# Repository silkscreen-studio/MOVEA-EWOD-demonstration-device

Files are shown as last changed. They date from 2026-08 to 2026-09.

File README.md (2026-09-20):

# MOVEA, an EWOD demonstration device

EWOD (ElectroWetting On Dielectric) is a fascinating process that moves droplets of water over an electrode array (dielectric as a medium), thanks to a high voltage (100+ V) applied between 2 adjacent cells (coplanar capacitance). **MOVEA** is a minimal 4x4 EWOD array with the complete driver board to demonstrate the basic principle of electrowetting. Based around an ESP32-C3, a DC DC boost converter module (168V OUT) as well as the HV509 driver IC. All inside a fully enclosed 3D printed device. 

<p align="center">
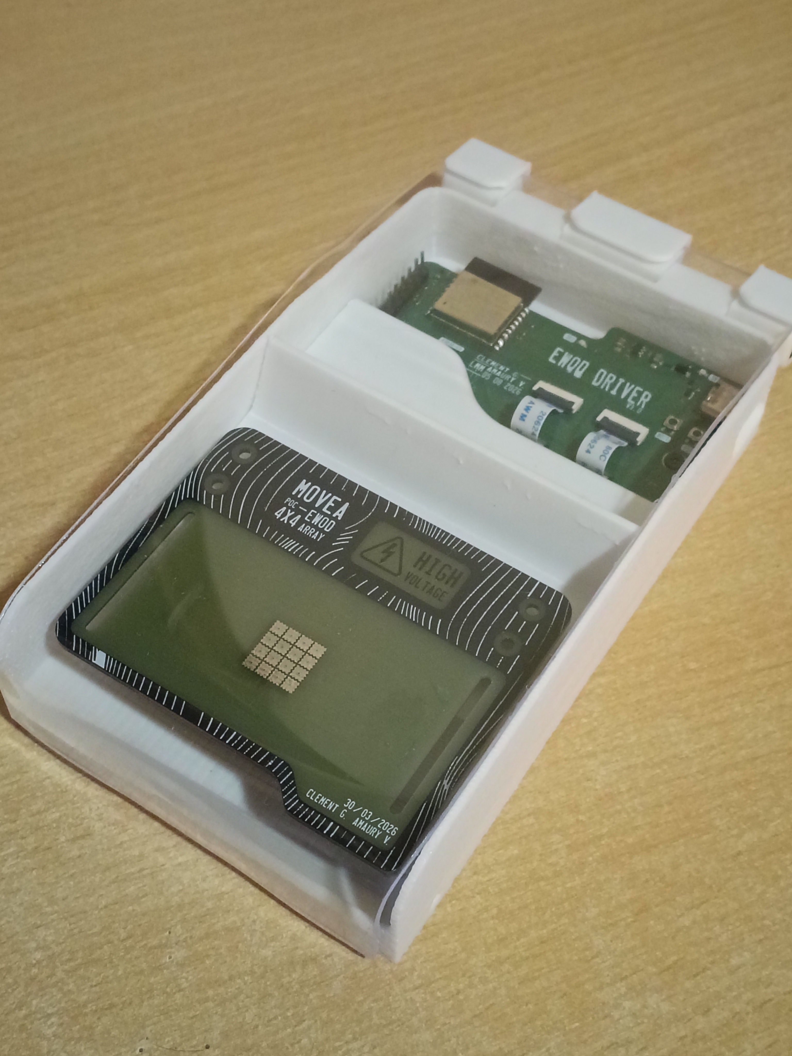
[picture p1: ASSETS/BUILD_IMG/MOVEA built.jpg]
MOVEA BUILT

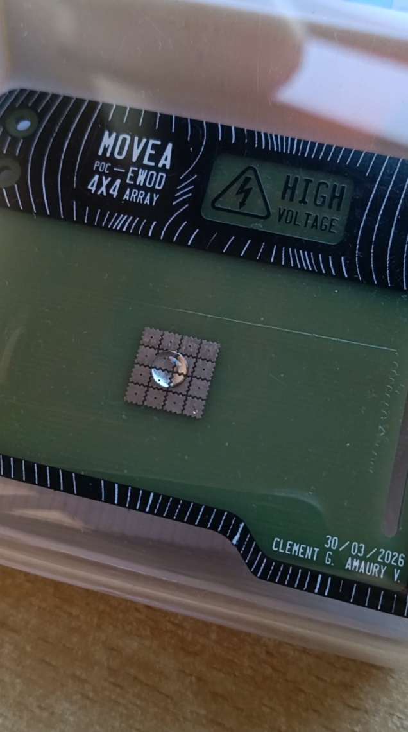
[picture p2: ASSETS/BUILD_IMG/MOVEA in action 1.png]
MOVEA in action

</p>

> [!CAUTION]
> **HIGH VOLTAGE**
>
> This project generates high voltage (~168V DC) from the USB C to correctly drive the EWOD electrodes.
> While I tried my best to provide a fully enclosed design with the HV part being detachable from the MCU circuitry, the high voltage side remains **not galvanically isolated** from the MCU side. Treat the whole board as live whenever `HV OUT` is enabled, not just HV traces.
>
> The USB isn't galvanically isolated either, so it's recommended to fully disconnect the 2 FPC ribbon cables when programming the device to prevent any USB port damage in case of a failure. Controlling the device (droplet actuation) could then be done over WIFI.

> [!WARNING]
>
> **A few safety notes:**
> 
> Although I tried to design a fully enclosed device, the acrylic cover does not latch. Whenever high voltage is enabled, it is the user's responsibility to keep the acrylic door shut.
>
> I still added a 220k serie resistor right after the HV boost, which should limit the output current to completely safe levels of 750µA, but obviously the best practice is to not touch anything when the `HV` Rail is enabled.
>
> While the firmware demo already enforces this (could not be the case if a custom firmware is flashed). It is important to only enable the high voltage when actively actuating the droplets, and the `HV OUT` rail capacitors should be discharged in firmware after the HV module is disabled, to ensure `HV OUT` collapses instead of staying at 168V (the electrodes barely sink any current on their own). Collapsing `HV OUT` should obviously be done before switching the device off (because otherwise the N channel mosfet in charge of sinking `HV OUT` to ground won't conduct).

> [!WARNING]
> **No warranty, use at your own risk**: This project is provided as-is, without any guarantee of safety, correctness, or fitness for any purpose. If you do build, reproduce, adapt or take inspiration from this project, it's entirely at your own risk.
>
> I disclaim all responsibility for any damage, injury or other consequences arising from the use, reproduction, or modification of this design.

> [!NOTE]
> **Educational / demo purpose only** This project is intended for educational / demo purpose only, with no intent of being  used in actual lab experiments.

<br><br>

<br><br>
<br><br>

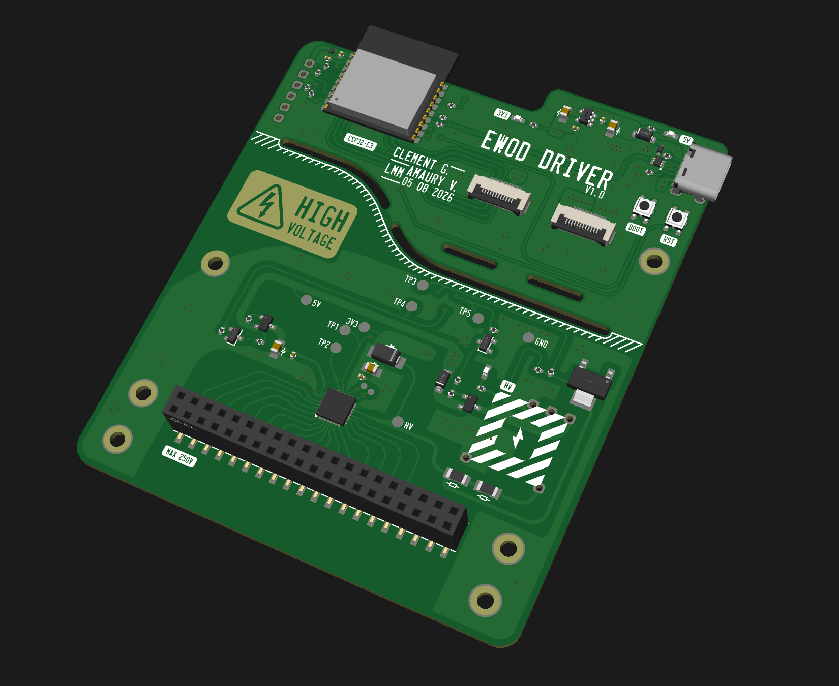
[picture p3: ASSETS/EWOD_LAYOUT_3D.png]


# What is EWOD?

Electrowetting is a fascinating branch of microfluidics, making possible to move droplets of water based solutions (µLiters of solutions) onto a flat surface without any mechanical part. EWOD has application in the biology industry (laboratories, ''lab on chip'') and in optical systems. By controlling each electrode with a 100+ V High voltage, the droplet position onto the EWOD grid can be controlled. 

# What this project aims to provide

This project is a minimal 4x4 EWOD device, with the FR4 EWOD array and the proper high voltage driver. The goal isn't to provide a finished lab-on-chip device with reservoirs and lab precision, but instead to obtain a small EWOD array that can move droplets on the 4x4 grid, showing the working principle of Electrowetting. Multiple dielectrics and different driving schemes could be used to evaluate different properties of electrowetting.

# Demos:

https://www.youtube.com/shorts/SwbNJbgiKzs

https://www.youtube.com/watch?v=05vwhufC6Lg

# Key features:

 - ESP32-C3 MCU
 - HV509 16 CH push pull HV driver
 - 3.3V-12V IN 168V OUT DC DC High voltage converter module
 - VIN enabled `HV OUT` rail (AO3415A P channel Mosfet)
 - 2x110k serie resistor directly on the HV boost output: should limit the current to a safe 750µA (in case of a downstream short circuit)
 - same 2x110k acting as bleeding resistors, sinking `HV OUT` to GND until the MCU disables it.
 - 2 FPC ribbon cables to be able to disconnect all HV related circuitry from the ESP32 devboard
 - detachable EWOD cartridge, that connects thanks to 2x20P 2.54mm Dupont Header pins.
 - 3D printed enclosure with acrylic cover to see the water droplet through the window.

# Schematic:

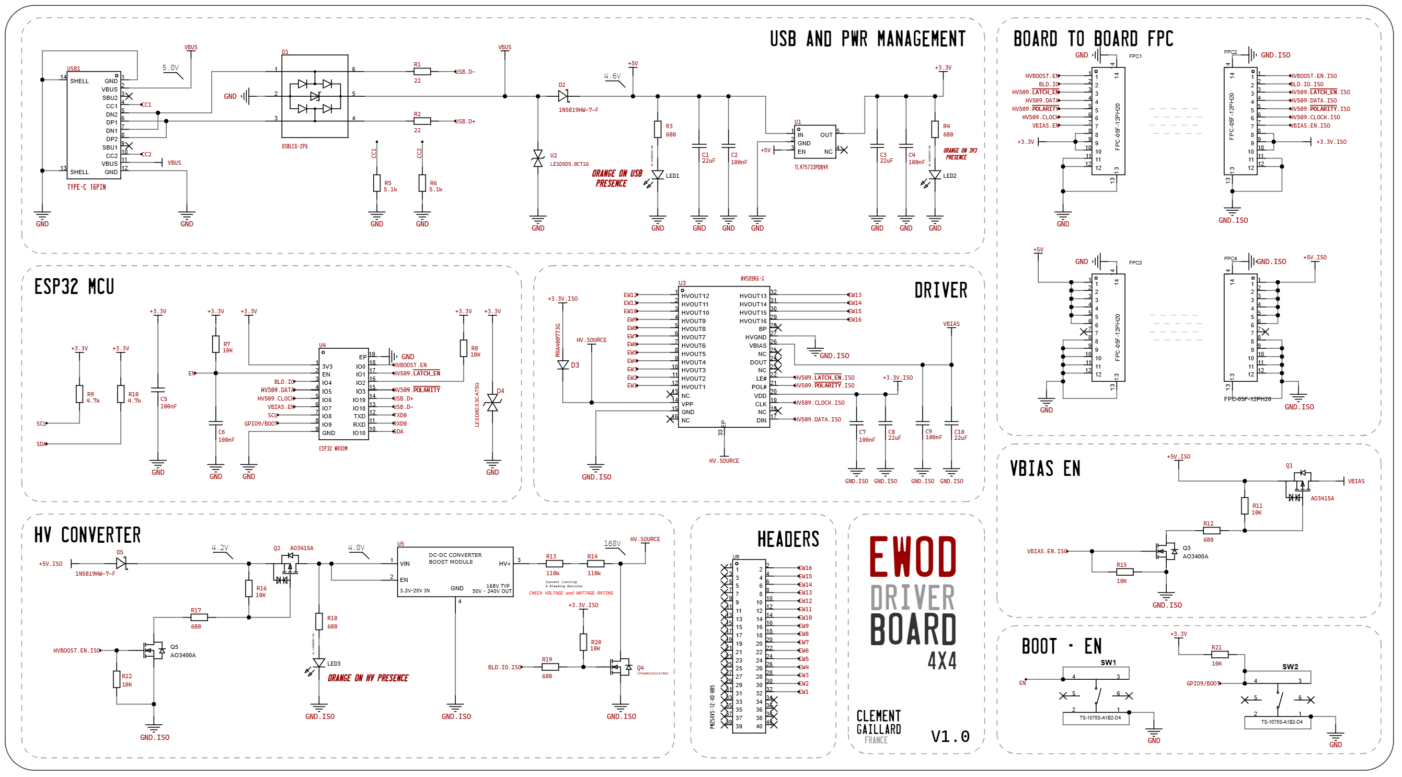
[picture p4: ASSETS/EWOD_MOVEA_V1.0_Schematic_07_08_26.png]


# Layout:

<p align="center">
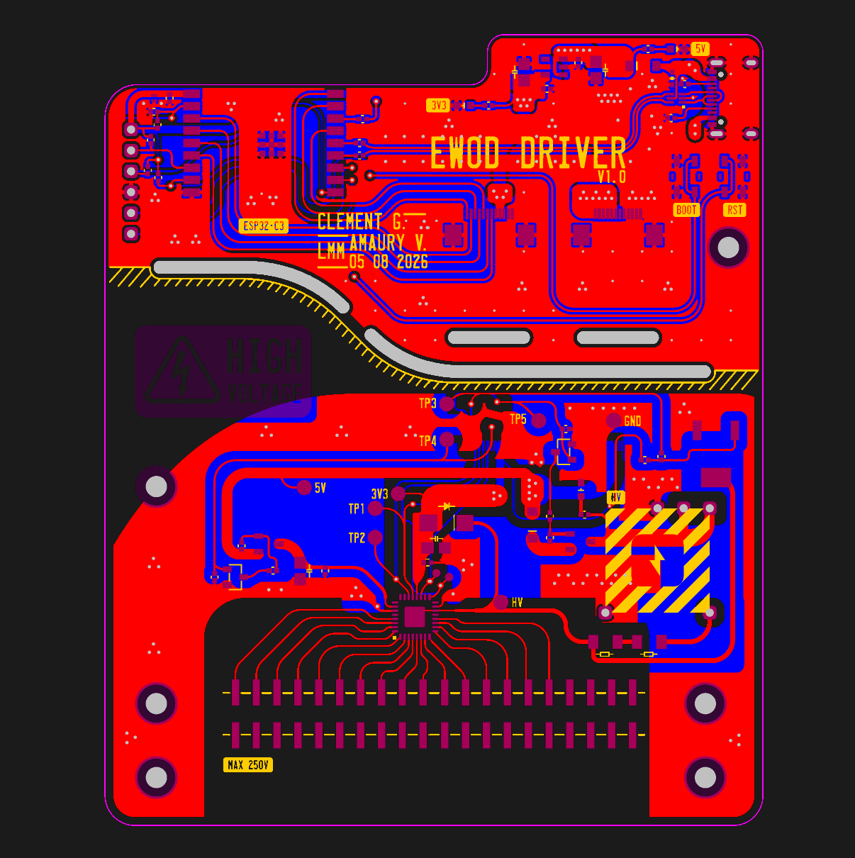
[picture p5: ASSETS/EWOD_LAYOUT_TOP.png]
Top layout

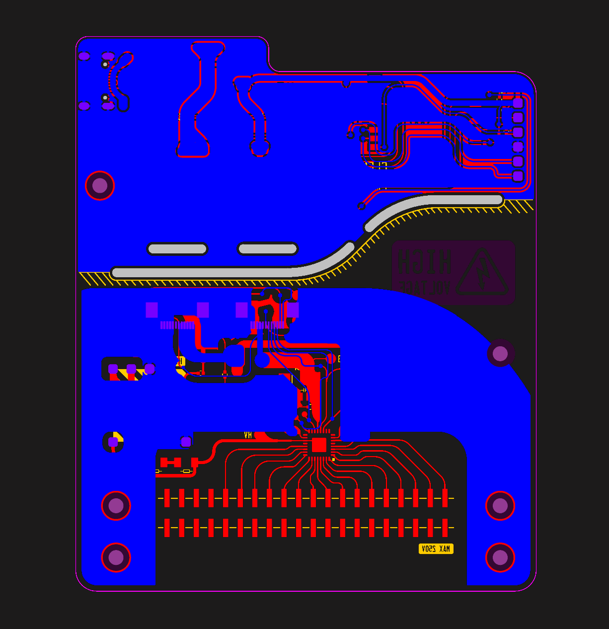
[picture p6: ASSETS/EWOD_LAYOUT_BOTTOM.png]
bottom layout

</p>

# Firmware:

A minimal demo code in C++ (Arduino IDE) is available to interface the HV509 as well as controlling the different power mosfets.

# Enclosure Assembly:

After 3D printing the different parts, cutting a 78.5mm long Φ 6mm steel rod and creating the acrylic window (2mm rectangle cut from an acrylic sheet, then bent with a hot air gun), the device can be assembled:
After connecting the 2 FPC ribbon cables, the PCB can be securely mounted to the enclosure thanks to threaded inserts added beforehand, and the HV cover can be glued in place (held in place with the 2 side rails). for the window, it's recommended to create a 'chain' with all the hinges placed on the enclosure with the rod in the middle, before gluing the acrylic window to the 3 hinge parts.

> [!NOTE]
> **POST BUILD EDIT**
> Bending the acrylic with the hot air gun wasn't really easy, the round 90° angle turned out pretty good, but the 10° angle near the hinge ended up offset...

<br><br>

<p align="center">
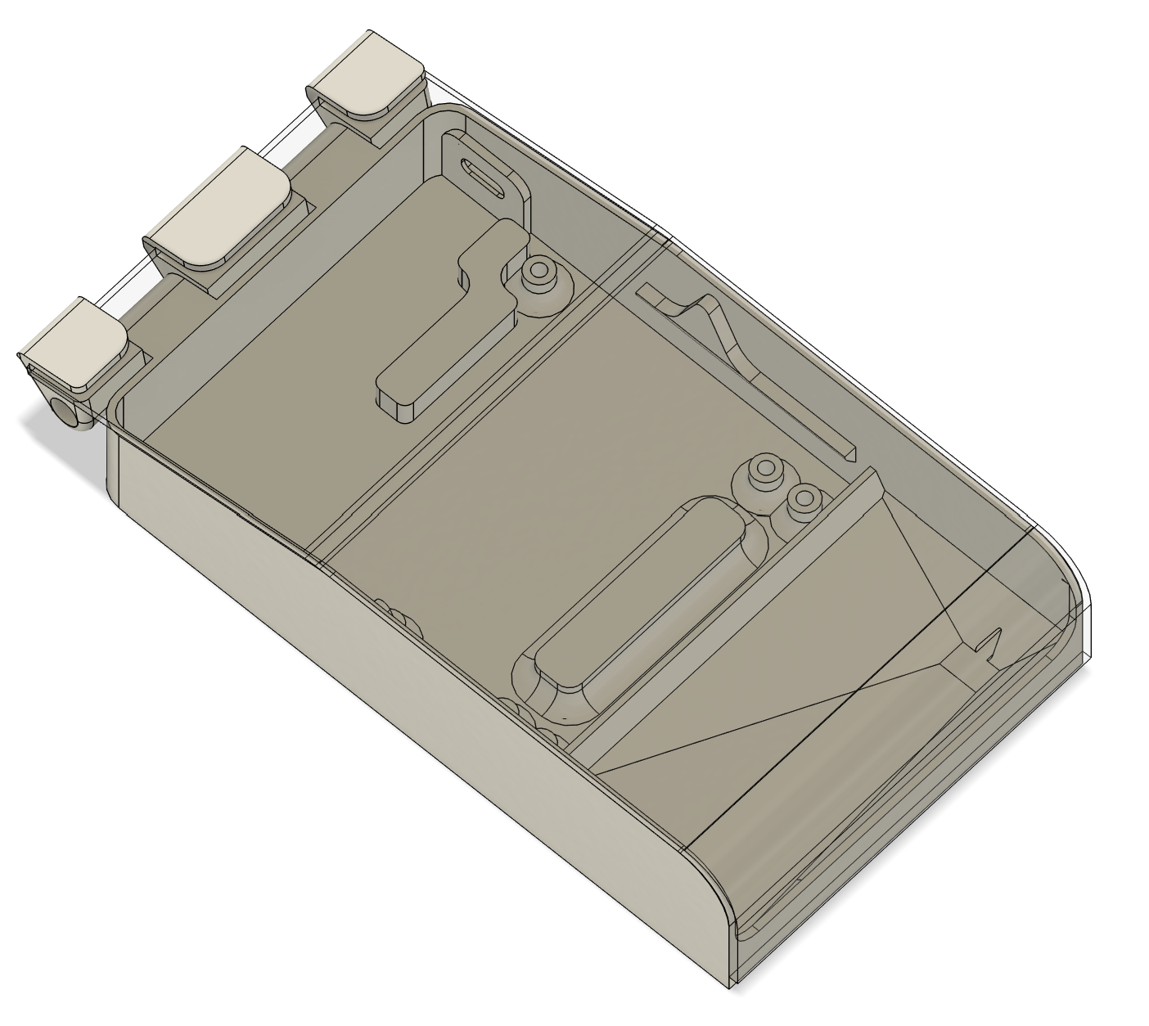
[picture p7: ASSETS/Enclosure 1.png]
3D Enclosure IMG 1

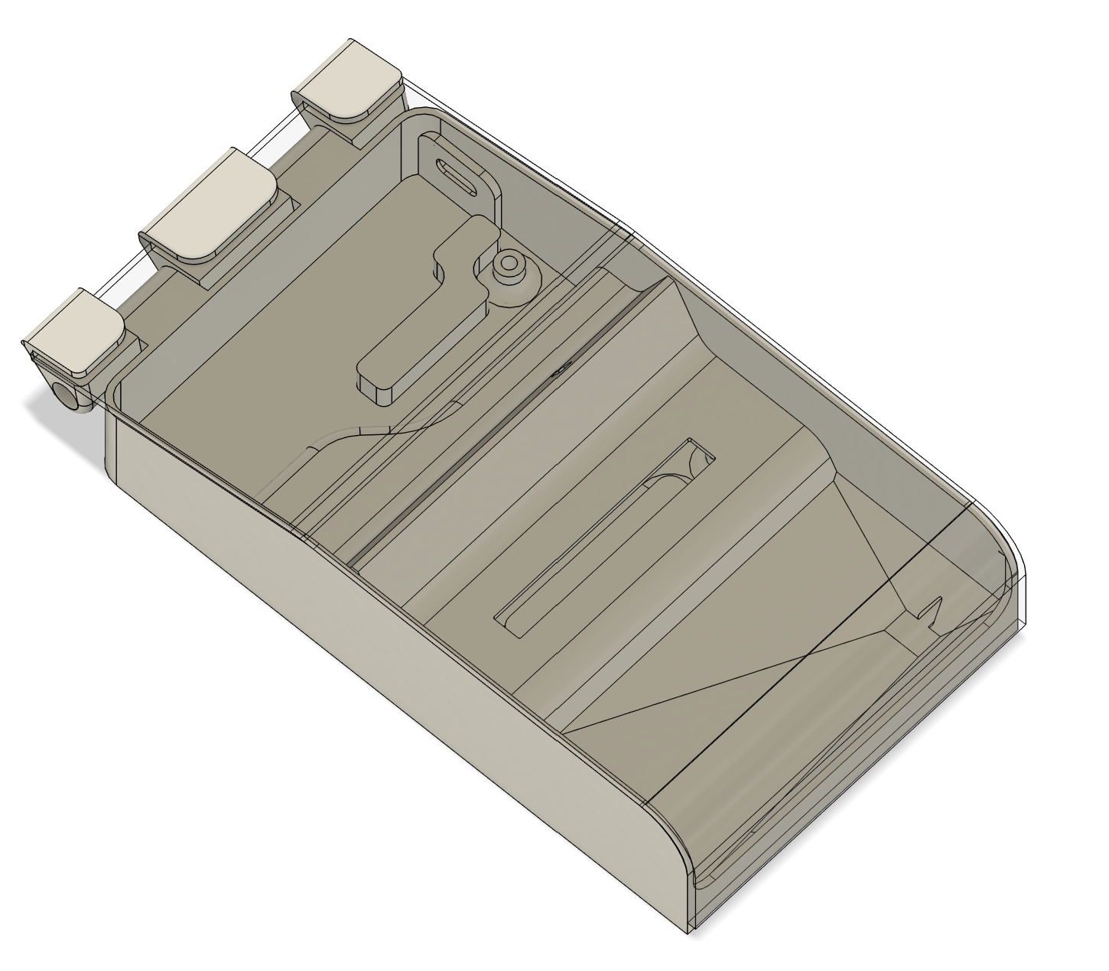
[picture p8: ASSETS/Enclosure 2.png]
3D Enclosure IMG 2

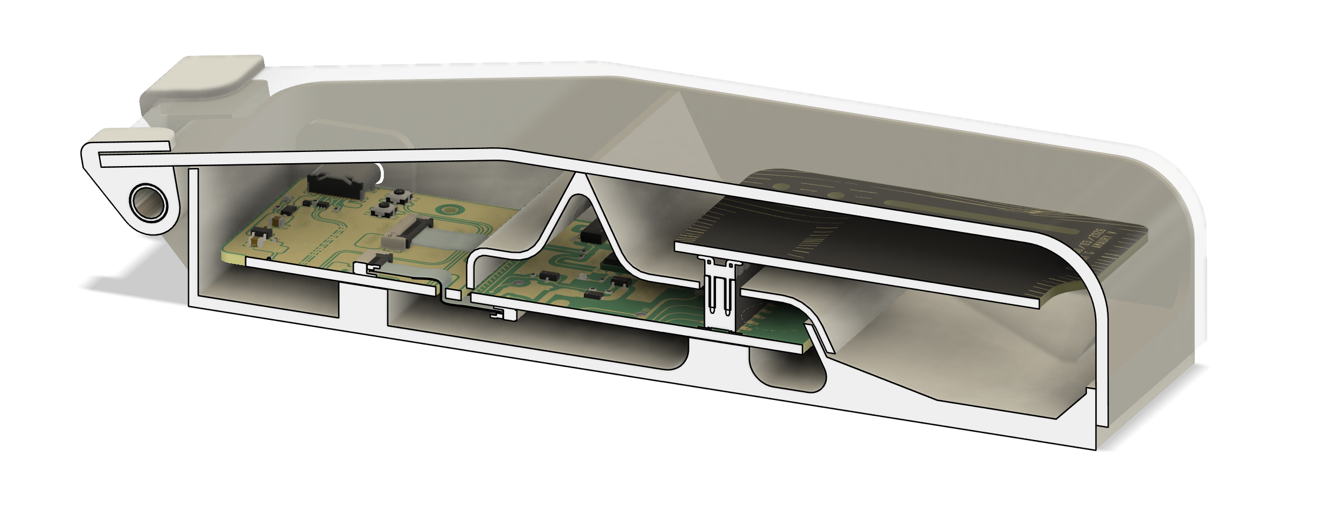
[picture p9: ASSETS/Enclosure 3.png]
3D Enclosure IMG 3

</p>
<p align="center">
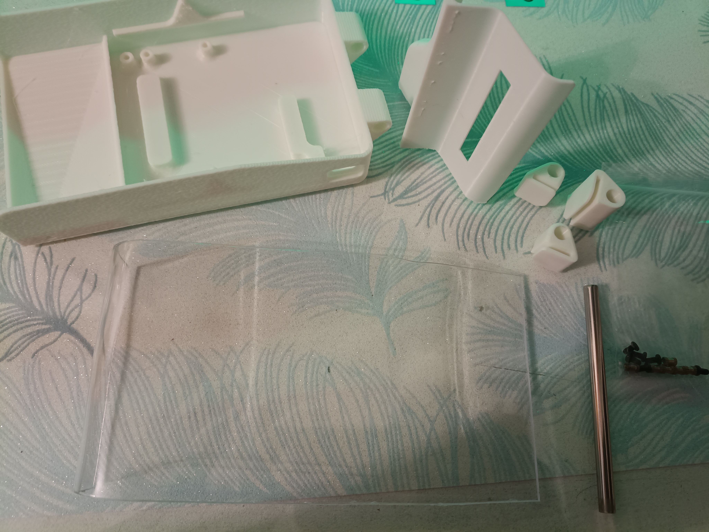
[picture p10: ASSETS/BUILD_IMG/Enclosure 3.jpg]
BUILD Enclosure IMG 3

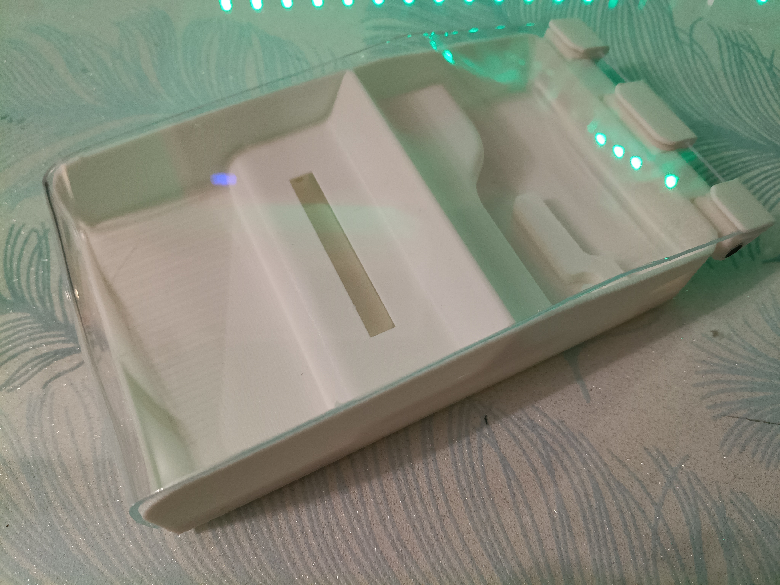
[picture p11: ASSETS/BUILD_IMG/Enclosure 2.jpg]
BUILD Enclosure IMG 2

</p>
<p align="center">
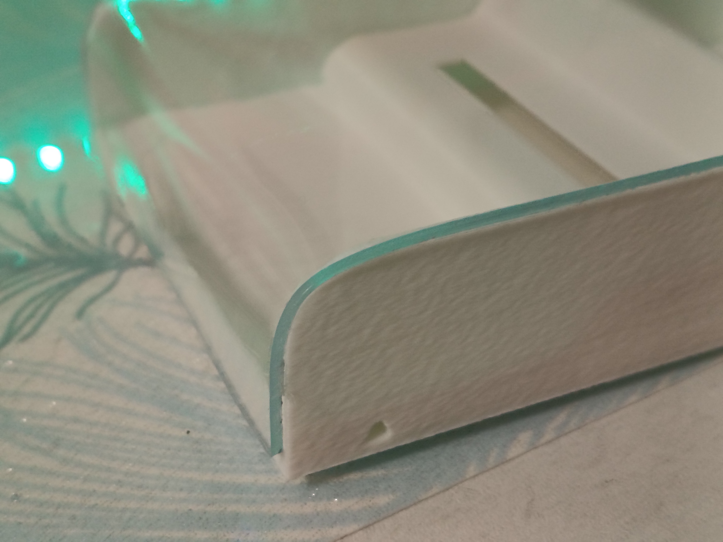
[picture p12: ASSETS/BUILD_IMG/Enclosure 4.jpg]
BUILD Enclosure IMG 4

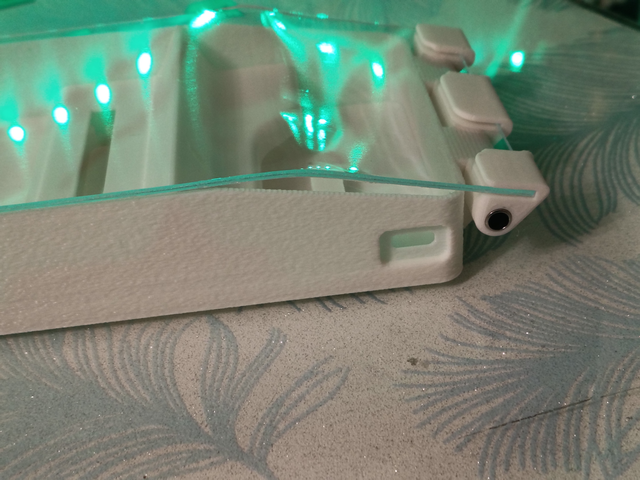
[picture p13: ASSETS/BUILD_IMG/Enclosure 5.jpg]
BUILD Enclosure IMG 5

</p>

<p align="center">
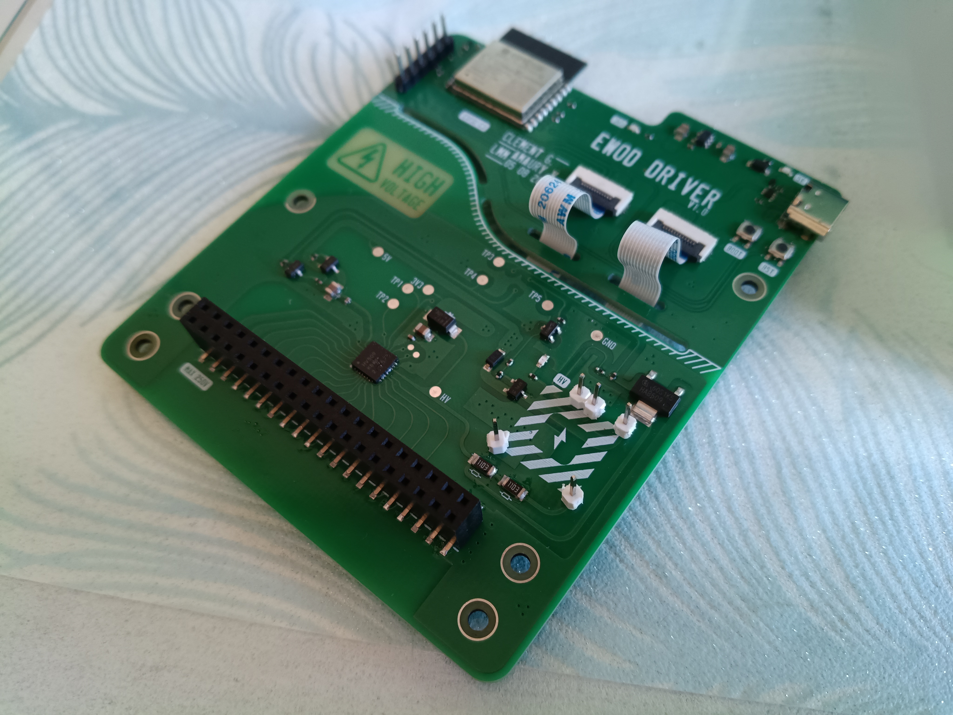
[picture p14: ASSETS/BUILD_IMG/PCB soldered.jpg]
PCB soldered

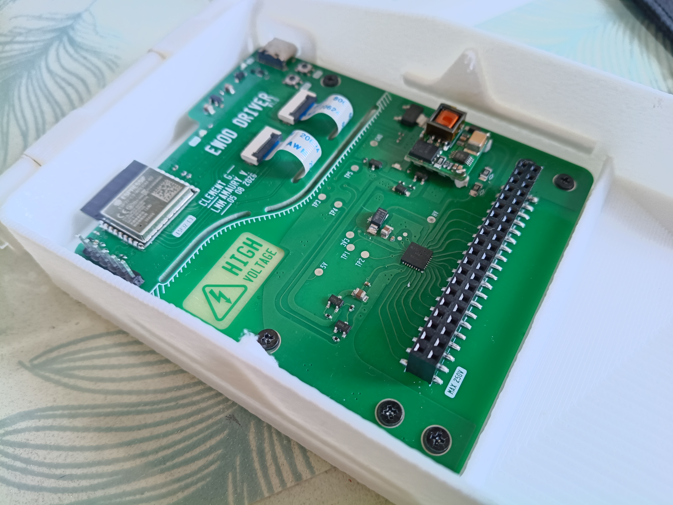
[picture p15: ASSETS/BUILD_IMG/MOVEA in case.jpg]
PCB in case

</p>

MOVEA built

# Preparing the device

the following sequence is for safely programming the device, and preparing the EWOD array.

 - Before plugging any USB power source, make sure the 2 FPC cables are disconnected (only connected on one end, at the bottom side of the board)
 - The ESP32 part only can then be programmed over USB (completely disconnected from any HV related circuitry, thus ensuring no failure can damage the USB port). To do so, plug the USB C cable, hold the BOOT button, press the RST button, release BOOT then flash the firmware. Disconnect the USB cable.
 - Prepare the EWOD PCB: after adding a thin layer of low viscosity silicon oil (5cst), stretch a piece of ParafilmM to be applied over the electrode Array, then after adding an additionnal thin oil layer and plugging the array PCB on the device, a small droplet of water (barely larger than an electrode) can be pladed on the array, then discharged from any residual static charge with a GND wire
 - Carefully reconnect both FPC cables, and close the acrylic cover before reconnecting a USB power source

> [!NOTE]
> **POST BUILD EDIT**
>   I couldn't stretch the parafilm correctly, so it obviously didn't work. However when testing other films I had at home, desk scotch worked quite well... This 31µm thin scotch was giving decent results (the actuation was a bit slow) but  with a proper 10 or 5µm dielectric film it should work even better. I'm planning on trying BOPP film and kapton tape. Both should work better.

# Render:

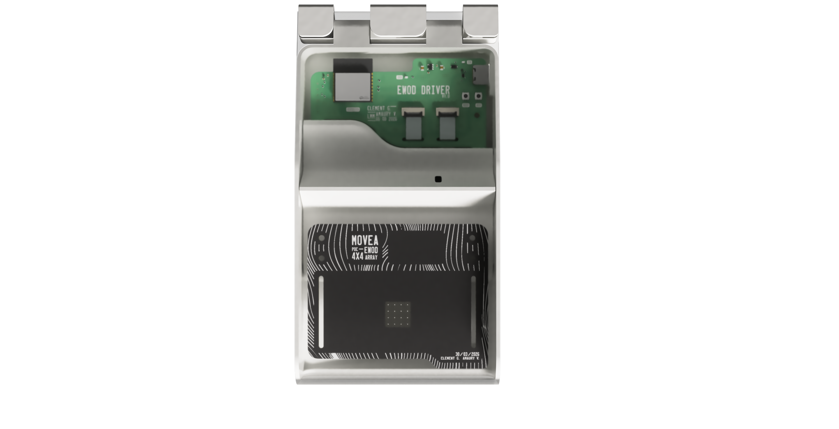
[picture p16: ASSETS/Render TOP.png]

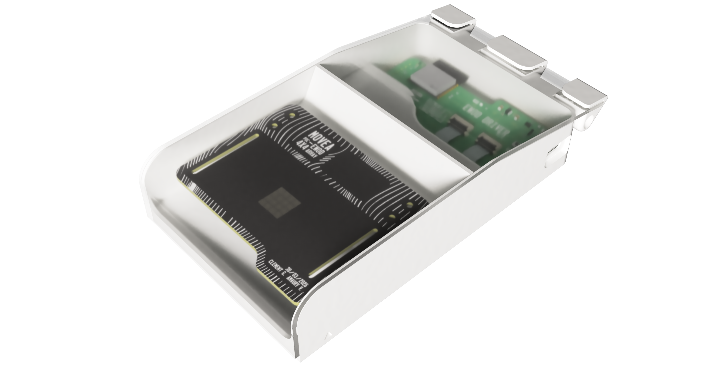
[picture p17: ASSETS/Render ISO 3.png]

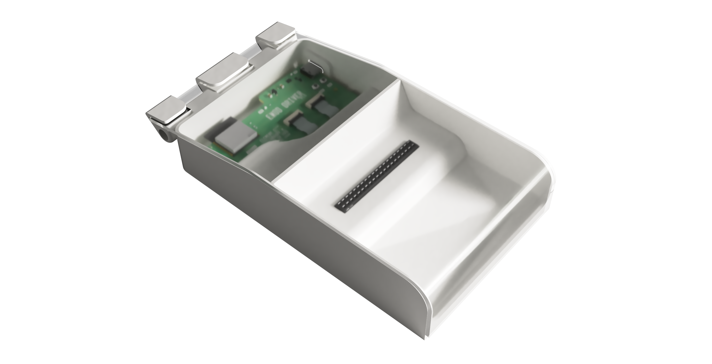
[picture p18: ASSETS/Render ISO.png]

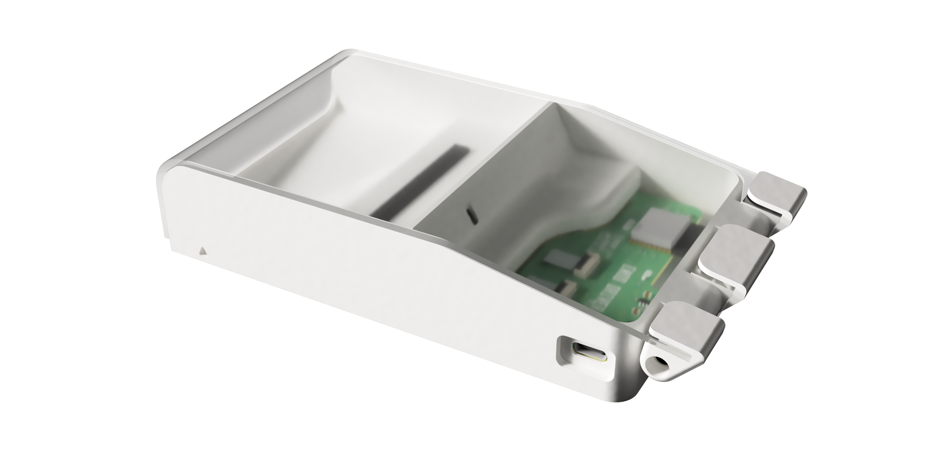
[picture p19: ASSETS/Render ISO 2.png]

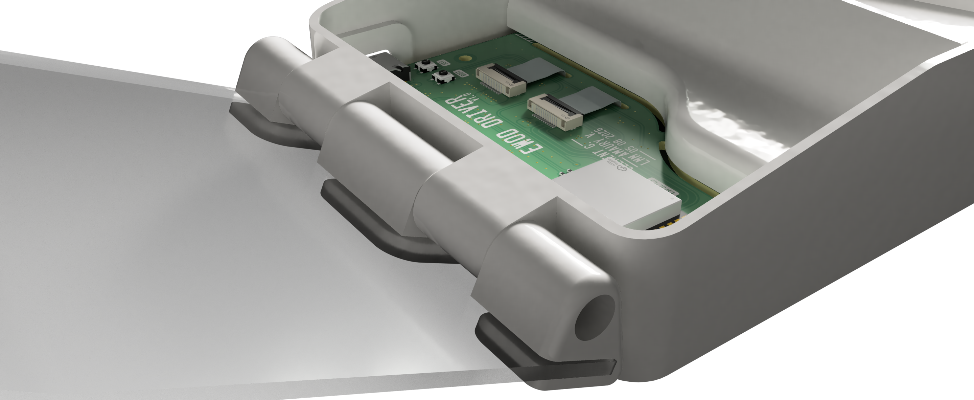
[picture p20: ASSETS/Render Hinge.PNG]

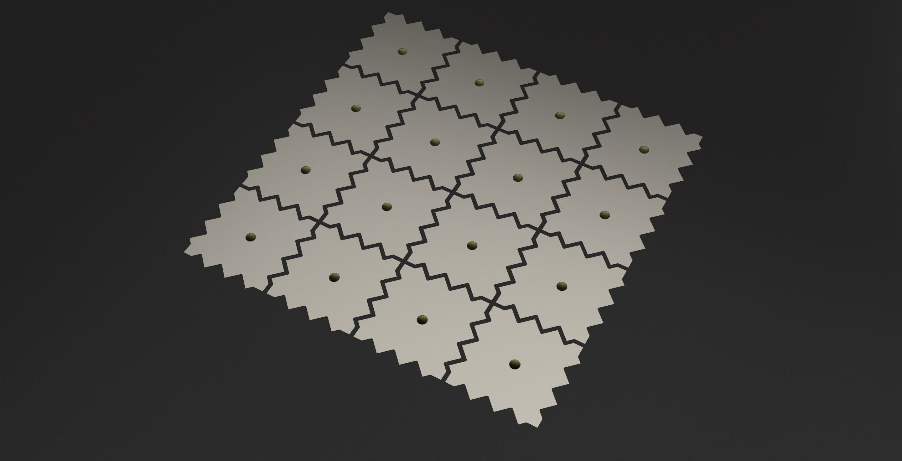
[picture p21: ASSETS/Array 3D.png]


# BOM

|Item |Quantity|Designator |Value |Manufacturer Part |LCSC Part|Link |Price [MOQ] |Total Price (1 board & 5 cartridge)|
|---|---|---|---|---|---|---|---|---|
|MLCC 0805 |4 |C1 C3 C8 C10 |22uF |CL10A226MP8NUNE |C86295 |https://www.lcsc.com/product-detail/C86295.html |$ 0.0537 [10] |$ 0.06 |
|MLCC 0402 |6 |C2 C4 C5 C6 C7 C9 |100nF |CL05B104KB54PNC |C307331  |https://www.lcsc.com/product-detail/C307331.html |$ 0.0096 [100]|$ 0.96 |
|USB ESD |1 |D1 | |USBLC6-2P6 |C15999 |https://www.lcsc.com/product-detail/C15999.html |$ 0.2787 [5]  |$ 1.39 |
|DIODE |2 |D2 D5 | |1N5819HW-7-F |C82544 |https://www.lcsc.com/product-detail/C82544.html |$ 0.0568 [10] |$ 0.57 |
|HV DIODE |1 |D3 | |MRA4007T3G |C47921 |https://www.lcsc.com/product-detail/C47921.html |$ 0.0942 [10] |$ 0.94 |
|ESD DIODE |1 |D4 |3.3V |LESD8D3.3CAT5G |C5563754 |https://www.lcsc.com/product-detail/C5563754.html |$ 0.0090 [20] |$ 0.18 |
|FPC Connector |4 |FPC1 FPC2 FPC3 FPC4 | |FPC-05F-12PH20 |C2856799 |https://www.lcsc.com/product-detail/C2856799.html |$ 0.1079 [5]  |$ 0.54 |
|Orange LED |3 |LED1 LED2 LED3 | |XL-1608UOC-06 |C965800  |https://www.lcsc.com/product-detail/C965800.html |$ 0.0068 [100]|$ 0.68 |
|P Mosfet |2 |Q1 Q2 | |AO3415A |C133233  |https://www.lcsc.com/product-detail/C133233.html |$ 0.1033 [5]  |$ 0.52 |
|N Mosfet |2 |Q3 Q5 | |AO3400A |C20917 |https://www.lcsc.com/product-detail/C20917.html |$ 0.0849 [5]  |$ 0.42 |
|HV N Mosfet |1 |Q4 | |IPN60R1K5CEATMA1 |C3288802 |https://www.lcsc.com/product-detail/C3288802.html |$ 0.5529 |$ 0.56 |
|Chip Resistor 0402 |2 |R1 R2 |22 |AC0402JR-0722RL |C144722  |https://www.lcsc.com/product-detail/C144722.html |$ 0.0027 [100]|$ 0.27 |
|Chip Resistor 0402 |6 |R3 R4 R12 R17 R18 R19 |680 |RC0402FR-07680RL |C137948  |https://www.lcsc.com/product-detail/C137948.html |$ 0.0054 [100]|$ 0.54 |
|Chip Resistor 0402 |2 |R5 R6 |5.1k |RC-02K512JT |C453708  |https://www.lcsc.com/product-detail/C453708.html |$ 0.0027 [100]|$ 0.27 |
|Chip Resistor 0402 |8 |R7 R8 R11 R15 R16 R20 R21 R22|10K |RC0402JR-7W10KL |C851859  |https://www.lcsc.com/product-detail/C851859.html |$ 0.0045 [100]|$ 0.45 |
|Chip Resistor 0402 |2 |R9 R10 |4.7k |RC0402FR-074K7L |C105871  |https://www.lcsc.com/product-detail/C105871.html |$ 0.0043 [100]|$ 0.43 |
|HV Chip Resistor 1206 200V 250mW rated|2 |R13 R14 |110k |RT1206BRD07110KL |C870372  |https://www.lcsc.com/product-detail/C870372.html |$ 0.073 [10]  |$ 0.73 |
|Push-button |2 |SW1 SW2 | |TS-1075S-A1B2-D4 |C492872  |https://www.lcsc.com/product-detail/C492872.html |$ 0.067[10] |$ 0.67 |
|3V3 LDO |1 |U1 | |TLV75733PDBVR |C485517  |https://www.lcsc.com/product-detail/C485517.html |$ 0.2067[5] |$ 1.03 |
|ESD DIODE |1 |U2 |5V |LESD5D5.0CT1G |C7433850 |https://www.lcsc.com/product-detail/C7433850.html |$ 0.0148 [50] |$ 0.74 |
|HV Driver IC |1 |U3 | |HV509K6-G |C633266  |https://www.lcsc.com/product-detail/C633266.html |$ 4.3112 |$ 4.32 |
|MCU |1 |U4 |ESP32 WROOM |ESP32-C3-WROOM-02-N4|C2934560 |https://www.lcsc.com/product-detail/C2934560.html |$3.2954 |$3.30 |
|USB-C 16P |1 |USB1 | |TYPE-C 16PIN |C2765186 |https://www.lcsc.com/product-detail/C2765186.html |$ 0.0707 [20] |$ 1.41 |
|Female Header PIN |1 |U6 |2x20 |PM254VS-12-40-H85 |C5249780 |https://www.lcsc.com/product-detail/C5249780.html |$ 0.6594 |$ 0.66 |
|Male Header PIN (cartridge) |1 | |2x20 |PZ254-2-20-S |C3294478 |https://www.lcsc.com/product-detail/C3294478.html |$ 0.4758 |$ 2.38 |
| | | | | | | | | |
|BOOST converter | 1 | U5 | 168V OUT | | |https://fr.aliexpress.com/item/1005009055927625.html|$ 10.25 | $ 10.25 |
| | | | | | | | | |
|PCB Driver |1 | | | | |https://jlcpcb.com |$ 8.37 |$ 8.37 |
|PCB EWOD array |1 | | | | |https://jlcpcb.com |$ 8.37 |$ 8.37 |
|Metal Rod (hinge) Φ 6mm L >75mm | | | | | |https://fr.aliexpress.com/item/1005009347568195.html|$ 4.33 |$ 4.33 |
|3D Printed enclosure | | | | | | | | |
|2mm acrylic sheet | | |(min 200x100mm)| | | | | |
| | | | | | | | | |
| | | | | | |TOTAL | |$ 55.31 |

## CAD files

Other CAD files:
3D CAD/EWOD_MOVEA_driver_3D_model_05_08_26.step
3D CAD/EWOD_Movea_3DP_only.step
3D CAD/3D PCB Driver EWOD MOVEA V1.1.step
3D CAD/EWOD_MOVEA_driver_3D_model_05_08_26_FUSION360_files.f3z

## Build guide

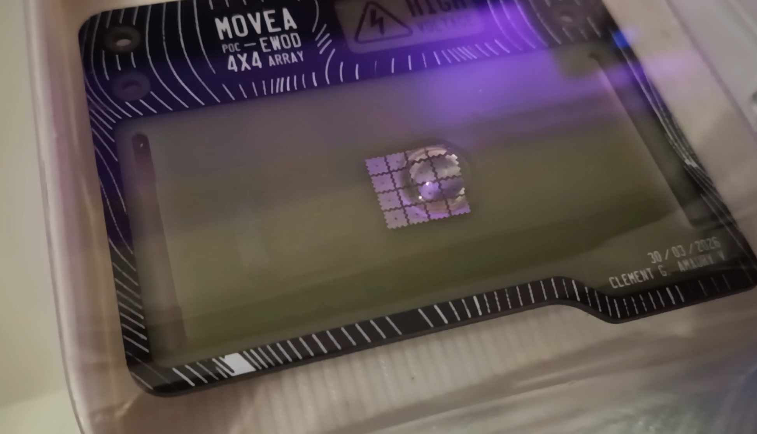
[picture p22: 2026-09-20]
ASSETS/BUILD_IMG/MOVEA in action 2.png

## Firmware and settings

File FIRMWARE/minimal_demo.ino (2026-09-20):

//    Minimal function implementation for driving the EWOD device.
//    By Clément G. - Silkscreen Studio - https://github.com/silkscreen-studio/MOVEA-EWOD-demonstration-device
//    Implements the HV509 shift register manipulation, HV boost proper enabling/disabling (including `HV OUT` 0V clamping management), and frequency-driven polarity inversion (AC actuation)

#define BLD_IO 4
#define VBIAS_EN 7
#define HVBOOST_EN 0

#define DATA 5
#define CLOCK 6
#define N_LATCH_EN 1
#define N_POLARITY 3

bool pol = 1;

void setup() {
  pinMode (BLD_IO, INPUT);    // HI-Z, pull up keeping the Bleeding Mosfet conducting

  pinMode (VBIAS_EN, OUTPUT);
  digitalWrite (VBIAS_EN, LOW);

  pinMode (HVBOOST_EN, OUTPUT);
  digitalWrite (HVBOOST_EN, LOW);

  pinMode (DATA, OUTPUT);
  pinMode (CLOCK, OUTPUT);
  pinMode (N_LATCH_EN, OUTPUT);
  pinMode (N_POLARITY, OUTPUT);

  digitalWrite (DATA, LOW);
  digitalWrite (CLOCK, LOW);

  digitalWrite (N_LATCH_EN, HIGH);
  digitalWrite (N_POLARITY, HIGH);

  delay (300);

  digitalWrite (VBIAS_EN, HIGH);
  Serial.begin(115200);
  delay (8000);    // to make sure I can actually upload a new sketch before it enables HV.
}

void loop() {

  HV_ENABLE();
  delay (4000);

 
  /*
  The electrodes are identified like this:
        6   /   8   /   10   /   12
        5   /   7   /   9    /   13
        4   /   3   /   11   /   14
        2   /   1   /   0    /   15
*/

 // Moving the droplet in circles

  
  moveCell (8);
  moveCell (10);
  moveCell (12);
  moveCell (13);
  moveCell (14);
  moveCell (11);
  moveCell (3);
  moveCell (7);
  }


void shiftData16 (uint16_t data) {
  for (uint8_t b = 0; b < 16; b++) {
    digitalWrite (DATA, (data >> b) & 0b0000000000000001);
    delayMicroseconds (1);
    digitalWrite (CLOCK, HIGH);
    delayMicroseconds (2);
    digitalWrite (CLOCK, LOW);
    delayMicroseconds (1);
  }
}

void pushDataLatch () {
  digitalWrite (CLOCK, LOW);
  delayMicroseconds (2);
  digitalWrite (N_LATCH_EN, LOW);
  delayMicroseconds (2);
  digitalWrite (N_LATCH_EN, HIGH);
}

void HV_ENABLE () {
  digitalWrite (HVBOOST_EN, HIGH);
  delay (750);   // HV output still clamped to GND, to cover the HV boost initial overshoot
  pinMode (BLD_IO, OUTPUT); // disable GND clamping: `HV OUT` rises
  digitalWrite (BLD_IO, LOW); //
}


void HV_DISABLE () {
  pinMode (BLD_IO, INPUT); // clamping `HV OUT` to GND
  digitalWrite (HVBOOST_EN, LOW); // disabling the HV BOOST
  delay (750); // discharging the HV output capacitors
}

void activateArrayAC(uint16_t freq, uint32_t duration) {  //ex: duration: 1000ms (1s) freq: 1000Hz (1kHz)
  if (freq == 0 || freq >= 65000) return;
  uint32_t timeStamp = millis();
  uint32_t halfPeriod = (uint32_t) (500000UL / freq);

  while (millis() - timeStamp <= duration) {
    pol = !pol;
    digitalWrite(N_POLARITY, pol);
    delayMicroseconds (halfPeriod);
  }
  digitalWrite(N_POLARITY, HIGH);
}

void moveCell (uint8_t cell) {        // The AC frequency actuation is implemented here directly by constantly changing the register values.
                                      // unlike toggling the POL pin, it doesn't change all the electrodes LOW (0V) to HIGH (168V) 
                                      // drawbacks: The actuation frequency can't be as high as if it was just toggling the POL pin, as the whole register needs to be rewritten
  for (uint16_t i = 0; i < 300; i++) {
      shiftData16 (0x0001 << cell);
      pushDataLatch();
      delay(3);
      shiftData16 (0x0000);
      pushDataLatch();
    }
}

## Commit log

2026-08-08 Track .f3d files with Git LFS
2026-08-08 Add STEP and Fusion360 files via LFS
    [3D PCB Driver EWOD MOVEA V1.1.step, EWOD_MOVEA_driver_3D_model_05_08_26.step, EWOD_MOVEA_driver_3D_model_05_08_26_FUSION360_files.f3z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]
